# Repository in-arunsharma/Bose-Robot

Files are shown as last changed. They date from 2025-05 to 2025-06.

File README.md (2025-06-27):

# Bose: A Stair-Climbing Robot for Hybrid Terrain Navigation

**An open-source, low-cost robot designed to autonomously climb stairs and navigate flat indoor environments using adaptive locomotion and onboard perception.**

---

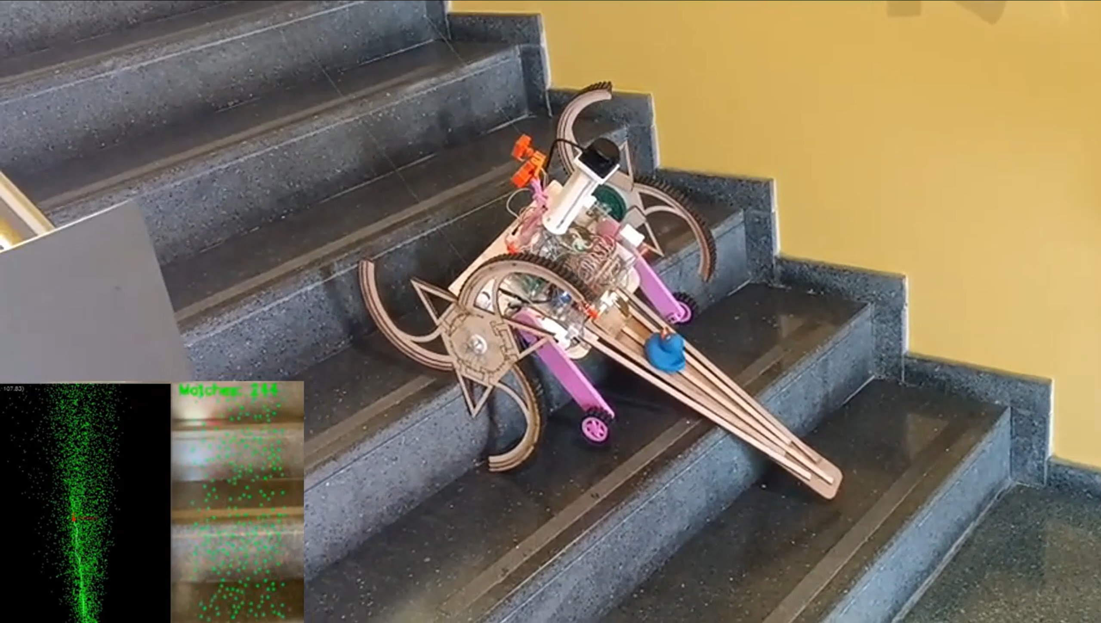
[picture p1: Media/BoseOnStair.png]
Bose Hero Image


---

## Table of Contents

- [Overview](#overview)
- [System Architecture](#system-architecture)
- [Repository Structure](#repository-structure)
- [Requirements](#requirements)
- [Installation](#installation)
- [Wiring and Setup](#wiring-and-setup)
- [How to Use](#how-to-use)
  - [Manual Control](#manual-control)
  - [SLAM and Navigation](#slam-and-navigation)
- [Mapping and SLAM](#mapping-and-slam)
- [Hardware Components](#hardware-components)
  - [Tri-Helix Wheels](#tri-helix-wheels)
  - [Retractable Wheels](#retractable-wheels)
  - [Support Tail](#support-tail)
- [Reproducibility](#reproducibility)
- [Citation](#citation)
- [Acknowledgments](#acknowledgments)
- [License](#license)

---

## Overview

**Bose** is a hybrid-terrain mobile robot capable of transitioning between stair-climbing and flat-ground modes through a custom tri-helix wheel system and retractable support wheels. Built around a Raspberry Pi 4 and designed for reproducibility and education, Bose combines real-time terrain classification, SLAM, and autonomous control in a lightweight, low-cost platform.

> 🧠 The robot is named after the **Bose-Einstein distribution**, reflecting its multi-modal adaptability and emergent behavior under constrained environments.

---

## Key Features

- Tri-helix wheel mechanism for stair traversal (up to 20 cm rise)
- Retractable micro wheels for efficient flat-ground navigation
- Real-time 2D SLAM with RPLIDAR C1 and monocular vision
- Terrain classification with ultrasonic sensor + camera
- Fully embedded system: runs on Raspberry Pi 4B (no external microcontroller)
- Modular, laser-cut chassis and 3D-printed mounts
- Reproducible architecture with open-source hardware and software

---

## Media & Demos

| Stair Climb | Terrain Switch | Visual SLAM |
|---|---|---|
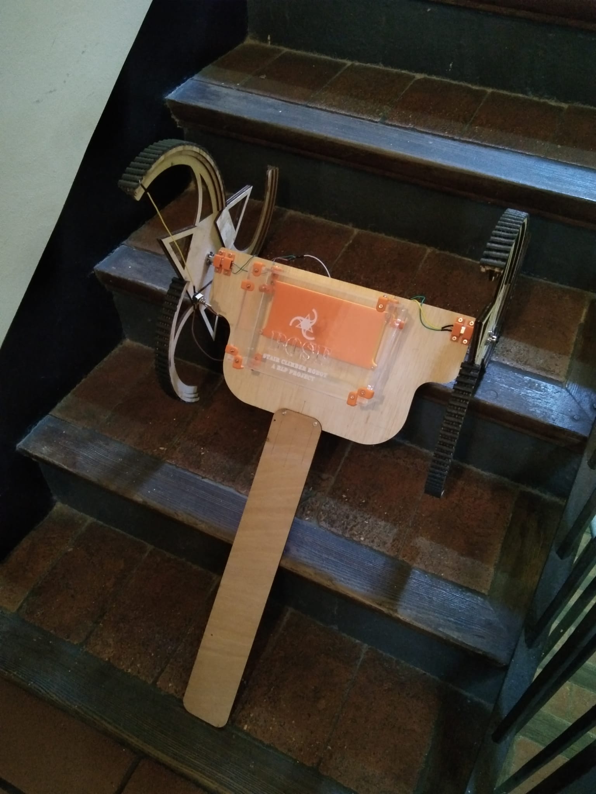
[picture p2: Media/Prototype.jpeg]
Stair Climbing
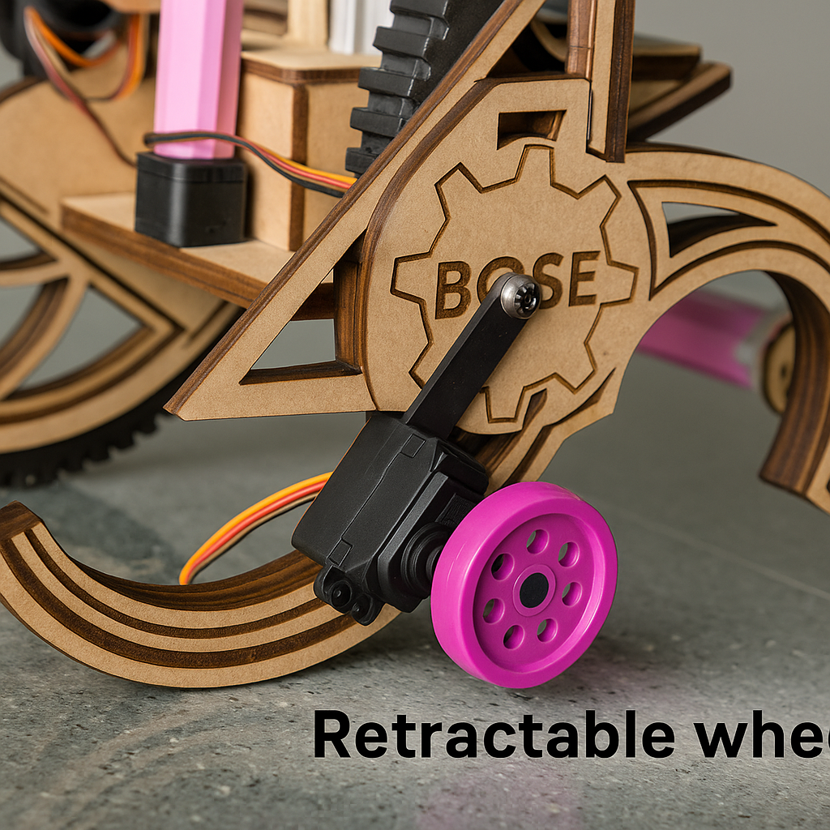
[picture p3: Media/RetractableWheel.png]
Terrain Switching
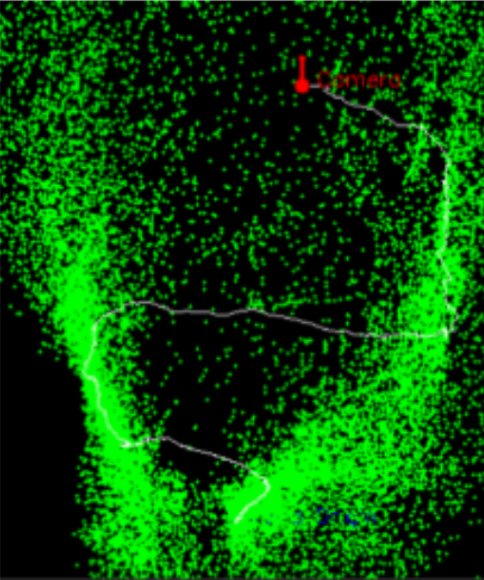
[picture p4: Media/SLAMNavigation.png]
SLAM Map
|  |  |  |

> See the full [demo video on YouTube](https://youtu.be/-nvnbL4hpCc)

---

## System Architecture

### Block Diagram

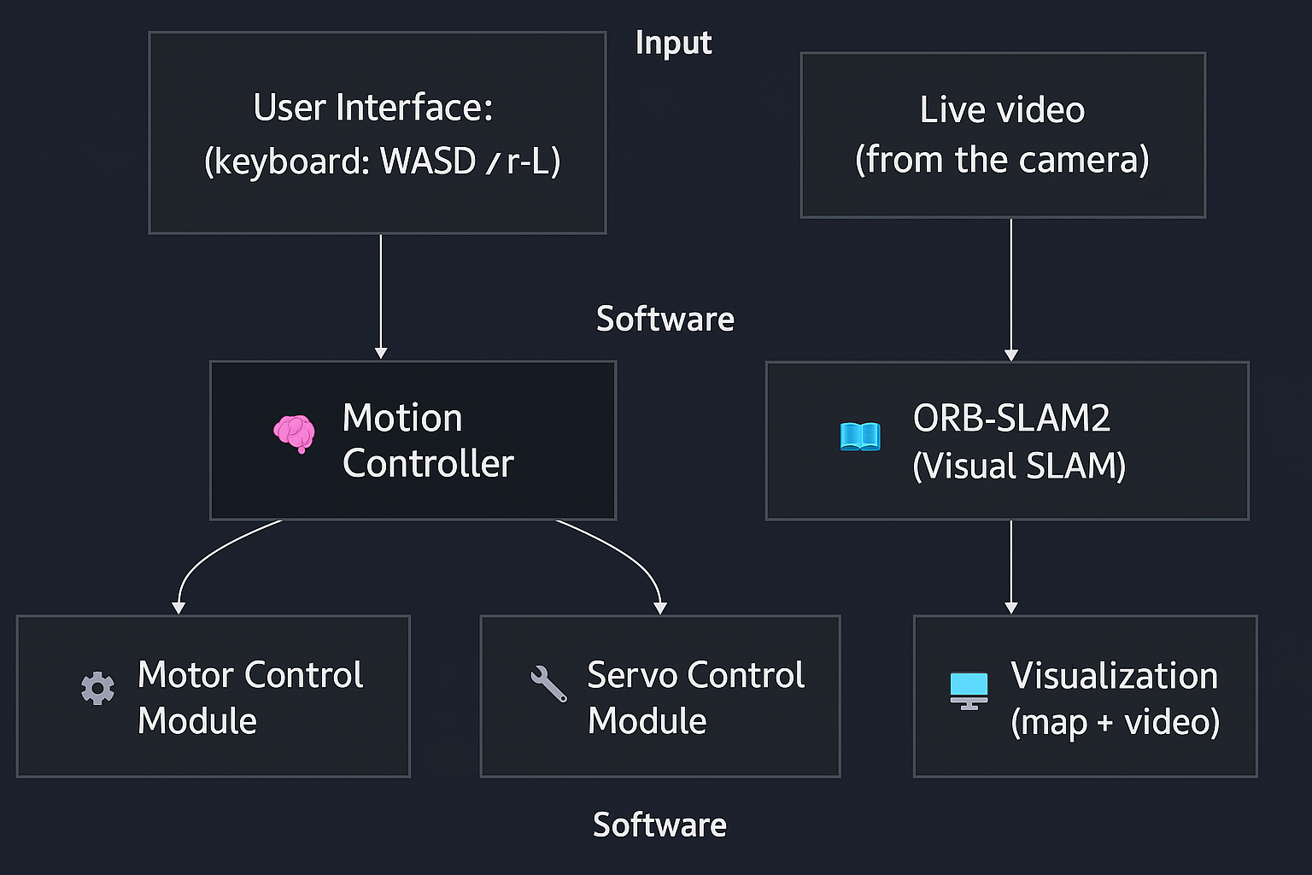
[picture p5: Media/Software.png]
System Architecture


### Hardware Stack

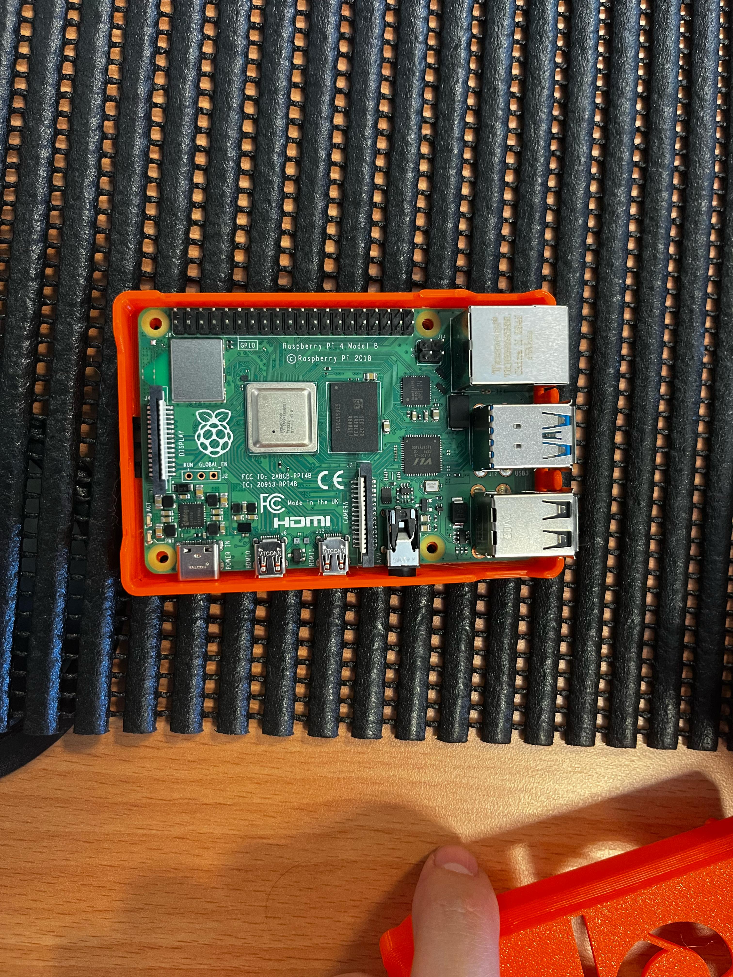
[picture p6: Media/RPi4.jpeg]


- Raspberry Pi 4B (4 GB RAM)
- MD25 Motor Controller (tri-helix wheels)
- L298N H-Bridge (retractable wheels)
- PCA9685 Servo Controller
- RPLIDAR C1 (USB)
- HC-SR04 Ultrasonic Sensor
- MPU6050 IMU
- Pi Camera v2 (8MP)
- 14.4V Li-ion Battery
- XL4015 and Pololu 5V 3A Buck Converters
- LEDs, push button, and MH Level Shifter

---

## 🛠️ Build Instructions

### Requirements

- Raspberry Pi 4B with Ubuntu 22.04
- ROS 2 Humble
- Python 3.10+
- Hardware: RPLIDAR C1, HC-SR04, MPU6050, PCA9685, MG996R servos, Maxon motors, etc.

Install dependencies:

```bash
sudo apt update && sudo apt install python3-pip
pip install adafruit-circuitpython-pca9685 smbus2 numpy opencv-python rplidar-robotics
```

## Repository Structure

```
├── docs/
│   └── logs/            # Logs of each working day
|   └── Paper.md         #IEEE Paper of the robot
├── hardware/
│   ├── Circuit/         # Fritzing schematics
│   └── DXF/             # 2D Drawings
|   └── STL/             # CAD models, STL files
├── software/
│   ├── raspberry4b-autonomous-lidar/           # Autonomus Code using RPLiDAR C1
│   ├── raspberry4b-remote/              # Manual Control Script
│   └── visual-slam/           # Visual SLAM Python Implementation
├── Media/                 # Photos and videos 
├── README.md
└── decisions.md           # Traceable engineering decisions
```

---

## Wiring and Setup

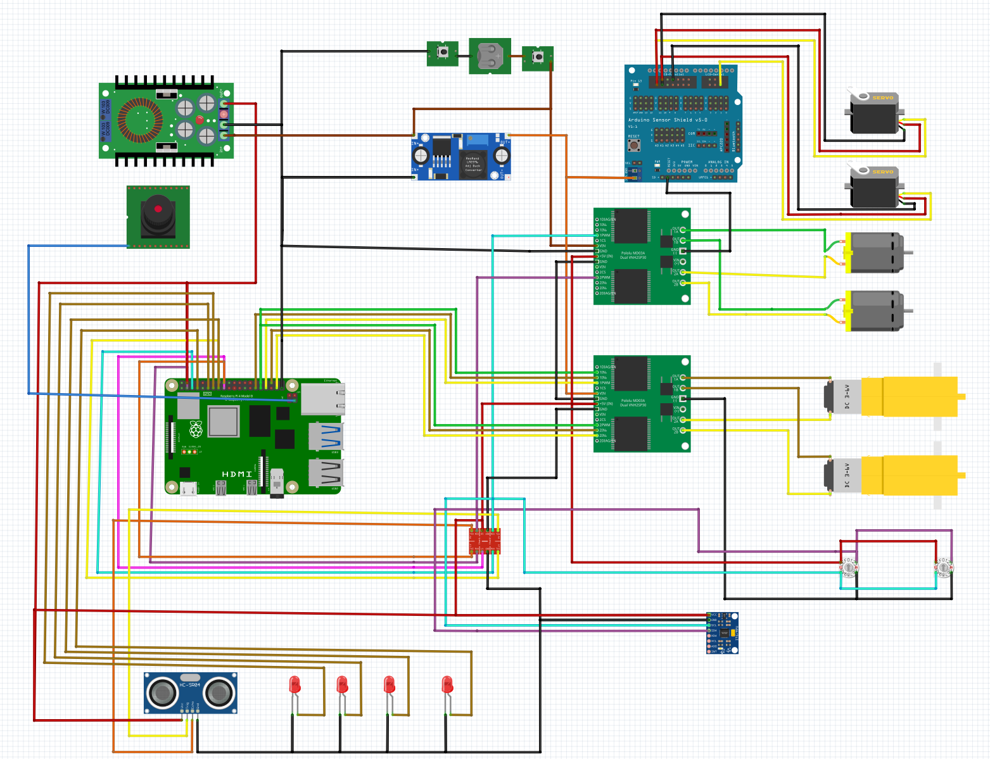
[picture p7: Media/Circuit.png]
BoseElectricCircuit

See `hardware/wiring_diagrams/raspberry_pi_wiring.pdf` for pinout.

> **Tip:** Use a 4700 μF capacitor near the Pi 5V rail to prevent brownouts during motor actuation.

---

## How to Use

### Manual Control (Interactive Script)

Run:

```bash
python3 scripts/interactive_control.py
```

**Controls:**

- Arrow keys: Helix motors  
- W / A / S / D: Retractable wheel motors  
- O / L: Lower / lift support wheels  
- Q: Quit

---

### SLAM and Navigation (ROS 2)

Launch ROS nodes:

```bash
source ~/ros2_ws/install/setup.bash
ros2 launch bose bringup.launch.py
```

**ROS 2 Topics:**

- `/scan` – RPLIDAR laser scan  
- `/odom` – Encoder-based odometry  
- `/imu/data_raw` – IMU orientation  
- `/camera/image_raw` – Pi camera feed

---

## Mapping and SLAM

Bose integrates:

- ORB-based monocular SLAM (via Pi Camera)
- 360º laser scanning (via RPLIDAR C1)
- Terrain detection (ultrasonic + vision)

A 2D occupancy map is built incrementally and used for localization and planning.

---

## Hardware Components

### Tri-Helix Wheels
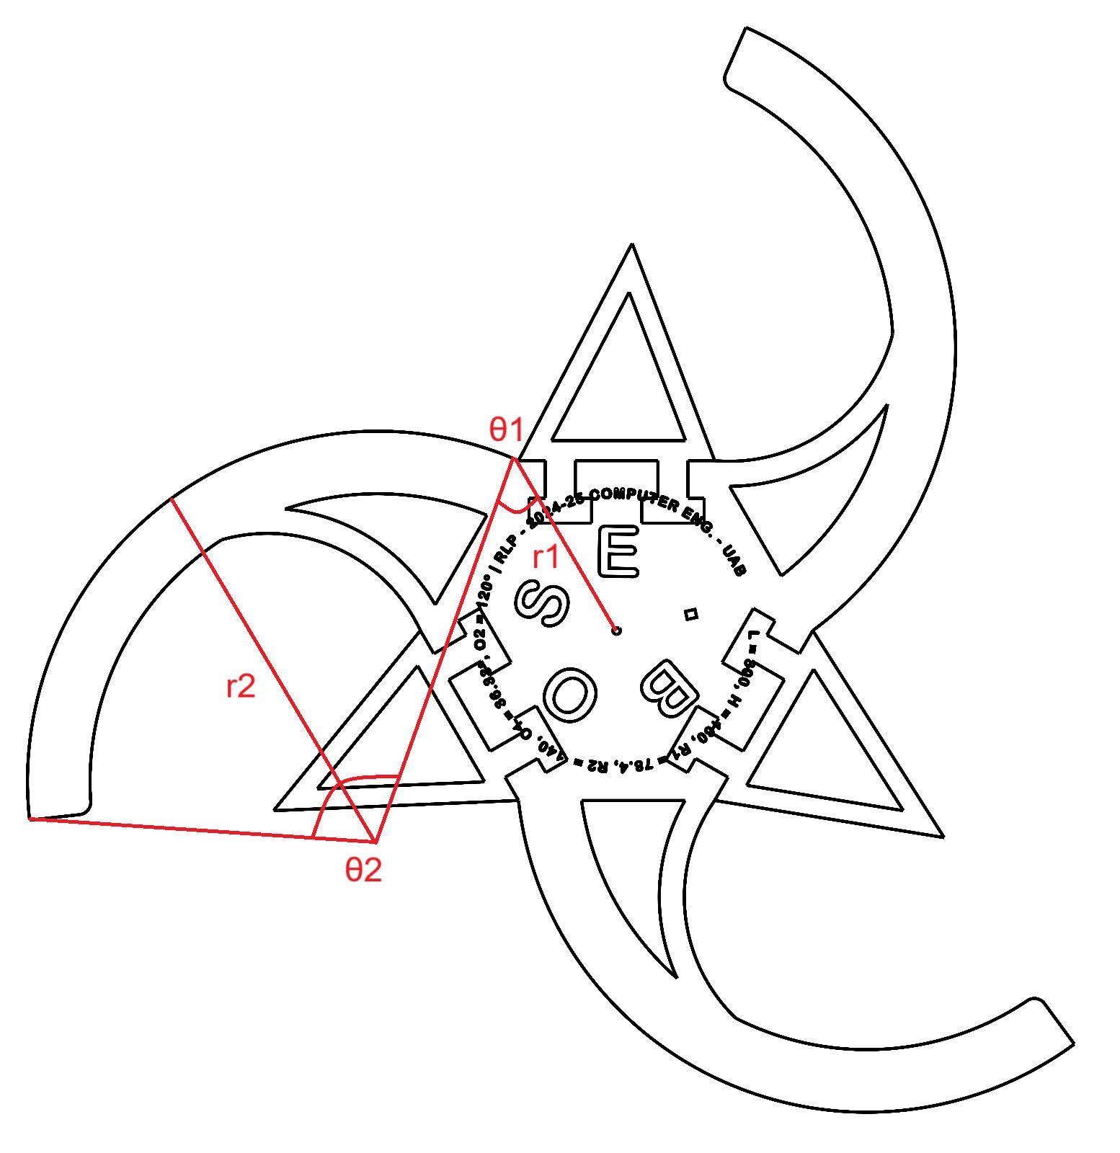
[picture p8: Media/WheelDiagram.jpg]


Laser-cut, three-lobed wheels for continuous stair climbing. Driven by Maxon motors with 785:1 gear reduction.

### Retractable Wheels

Pololu micro motors and MG996R servos enable flat-ground movement when the tri-helix wheels are lifted.

### Support Tail

A fixed rear extension adds stability on stairs without needing extra sensors or actuators.

---

## Reproducibility

To reproduce the robot:

1. Follow hardware instructions (CAD + wiring)
2. Flash Ubuntu 22.04 and install dependencies
3. Run the test scripts (manual or ROS-based)
4. Use `decisions.md` to trace engineering rationale

All firmware-free and open hardware. See `LICENSE`.

---

## Citation

**Arun Sharma**, **Pau Domínguez Ruiz**, **Gerard Souto Eslava**, **Chengjie Peng Lin**,  
*“Bose: A Stair-Climbing Robot for Hybrid Terrain Navigation,”* Universitat Autònoma de Barcelona, 2025.

```bibtex
@misc{bose2025,
  author      = {Sharma, Arun and Domínguez Ruiz, Pau and Souto Eslava, Gerard and Peng Lin, Chengjie},
  title       = {Bose: A Stair-Climbing Robot for Hybrid Terrain Navigation},
  year        = {2025},
  institution = {Universitat Autònoma de Barcelona},
  note        = {Bachelor’s Course in Computer Engineering}
}
```

---

## Acknowledgments

- Prof. Fernando L. Vilariño Freire  
- Prof. Carlos G. Calvo  
- Prof. Vernon S. Albayeros Duarte  
- Open Labs – Escola d’Enginyeria, UAB  
- Maxon Spain and Robot Electronics support teams

---

## License

This repository is licensed under the MIT License. See `LICENSE` for details.

> For academic use, extension, or replication, please contact the authors or contribute via GitHub issues and pull requests.

---

_"To climb stairs is to rise beyond limits. Bose takes that literally."_

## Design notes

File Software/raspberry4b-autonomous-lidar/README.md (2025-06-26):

# Exploración Autónoma 🧭

Este script busca que BOSE, equipado con un **RPLiDAR C1 – 360°**, explorar de forma autónoma y segura entornos potencialmente peligrosos (zona de rescate, desastres, entornos de riesgo, etc.).

- Realiza un **mapeado 2D en tiempo real** del entorno.  
- Se mueve tipo "Roomba": avanza, detecta obstáculos y cambia de rumbo.  
- Genera una visualización gráfica del mapa y del recorrido del robot.  
- Se basa en el controlador del motor MD25 y el sistema de LIDAR.

---

## Requisitos

- Python 3  
- Paquetes necesarios:
  ```bash
  pip3 install smbus2 numpy matplotlib rplidar

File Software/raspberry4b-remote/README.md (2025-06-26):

# Manual Control Script

Este script (`manual_control.py`) permite manejar a BOSE en Raspberry Pi 4 con:

1. **Tracción principal** (MD25) con teclas W/A/S/D  
2. **Ruedas retráctiles** (L298N) con flechas ↑/↓  
3. **Servos** (PCA9685) con O (subir) / L (bajar)  
4. **Salir** con E o Ctrl+C (detiene todo y limpia GPIO/I²C)

---

## Requisitos

- Python 3  
- Módulos:
  ```bash
  pip3 install smbus2 RPi.GPIO adafruit-circuitpython-pca9685 inputs

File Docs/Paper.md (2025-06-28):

# Bose: A Stair-Climbing Robot for Hybrid Terrain Navigation

**Arun Sharma**, **Pau Domínguez Ruiz**, **Gerard Souto Eslava**, and **Chengjie Peng Lin**  
School of Engineering, Universitat Autònoma de Barcelona, 08193 Bellaterra, Spain^[This project was completed as part of the bachelor’s course *Robotics, Language and Planning* (Spring 2025) in the Bachelor’s Degree programme in Computer Engineering.]
 
---

## Abstract
This paper presents Bose, a novel stair-climbing robot featuring an adaptive-wheel mechanism optimized for hybrid-terrain navigation. Addressing practical challenges in accessibility and autonomous indoor exploration, Bose employs two laser-cut tri-helix wheels for stair traversal, combined with smaller retractable wheels that activate during flat-surface navigation. An  tail mechanism maintains stability across diverse terrains. The robot integrates multiple onboard sensors, including an inertial measurement unit, ultrasonic range sensors, encoders, camera, and a 2D LiDAR, enabling terrain-aware locomotion and environment mapping. Terrain detection leverages computer vision and distance sensing, dynamically adjusting the wheel configuration based on real-time feedback. Key mechanical and control challenges, such as achieving sufficient torque-to-weight ratios and reliable transition between wheel modes, were systematically addressed. Experimental evaluations demonstrate Bose’s capability to autonomously climb standard stairs (up to 20 cm rise and 35° incline) and smoothly transition onto flat terrain at speeds up to 0.08 m/s. Additionally, real-time simultaneous localization and mapping (SLAM) facilitates autonomous navigation in unknown indoor environments. Future improvements will focus on enhancing adaptability through shape-shifting wheels capable of accommodating varied stair geometries, eliminating redundant wheel systems, and refining structural aerodynamics.
---
**Index Terms—** stair-climbing robot; tri-helix wheel; adaptive locomotion; hybrid-terrain navigation; low-cost robotics; SLAM.

---
## 1. Introduction
Mobile robots capable of traversing stairs unlock critical applications in urban logistics, assistive technologies, and disaster response. Current solutions, including tracked platforms such as the iRobot 510 PackBot [1][2] and legged systems like ANYmal [3], often exhibit significant trade-offs among speed, cost, and mechanical complexity. For instance, tracked robots typically climb standard stairs at speeds below 0.04 m·s⁻¹, while advanced quadrupedal robots rely on 12–18 high-precision actuators, elevating unit costs into the tens of thousands of USD.

This paper introduces **Bose**, a low-cost robotic platform designed to autonomously and efficiently navigate hybrid terrains—flat surfaces and stairways—by employing a novel adaptive wheel mechanism. Unlike conventional tracked or purely legged solutions, Bose utilizes laser-cut tri-helix wheels specifically optimized for rapid stair traversal, complemented by small retractable wheels activated for efficient flat-ground navigation. Terrain-adaptation is achieved through real-time fusion of monocular vision, ultrasonic ranging, wheel odometry, and 2D LiDAR data, enabling transitions between wheel modes in under 50 ms. A custom drivetrain delivers a peak torque of approximately 10 N·m per 0.22 m diameter wheel, keeping total mass below 3 kg and material costs under 500 USD.

The primary contributions of this work are threefold:

- An adaptive wheelset mechanism that doubles stair-climbing speed compared to tracked robots of similar mass.
- A lightweight perception stack capable of achieving terrain-classification accuracy above 95%, implemented on a Raspberry Pi 4.
- An open-source hardware and software framework facilitating replication and further research.

Experimental validation conducted on standard stairs (16 cm rise, 30 cm tread) demonstrated reliable ascent and descent at speeds up to 0.08 m·s⁻¹, maintaining pitch deviations below 5°. Additionally, Bose navigated 50 m of mixed indoor terrain without human intervention.

The robot is named Bose, inspired by the Bose–Einstein distribution—an allusion to its multi-modal adaptability and emergent behavior under constrained conditions. Like the physical phenomenon, the robot seeks to exhibit coherent, unified responses across varying environments.

The remainder of the paper is structured as follows: Section 2 provides a review of related work. Section 3 describes the proposed robotic architecture. Sections 4–6 detail mechanical, electronic, and software design. Sections 7 and 8 present the experimental methodology and corresponding results. Section 9 discusses the broader implications of these findings. Section 10 concludes the paper and highlights avenues for future development.

---
## 2. State of the Art

Stair negotiation remains an open problem in mobile robotics. Prior work spans six mechanical paradigms, each trading off speed, cost, and fabrication complexity. Below we summarise the dominant approaches and assess their suitability for low-cost academic prototypes.

### 2.1 Lifting or Pivot-Hoist Platforms  
Early robots such as CMU’s URBOT (1993) elevate the chassis with powered arms to surmount each step. Although conceptually simple, hoist mechanisms demand >20 N m joint torques and suffer cycle times of 6–10 s per step, limiting practicality on long staircases [4].

### 2.2 Pure Traction Wheels  
Four-wheel differentially driven platforms rely on tyre friction and wheelbase shift (e.g., Asguard V2 [5]). They are lightweight (<3 kg) but stall on 17 cm stair risers unless equipped with exotic rubber compounds or active suspension.

### 2.3 Articulated Multi-Wheel Sets  
Six-wheel rovers with rocker-bogie or flipper arms (e.g., the Mars Exploration Rover mobility system [6]) add contact points and passive compliance. Complexity rises sharply: typical hobby-grade builds require 12 bearings and 4 gearboxes, yet still climb stairs at ≤0.05 m s⁻¹.

### 2.4 Helical Tri-Wheel Mechanisms  
Tri-star and spiral wheels rotate successive lobes onto the next tread, enabling quasi-continuous ascent. NASA’s Athlete and the TriStar prototype [7] reach 0.08–0.12 m s⁻¹ on 17 cm stairs while using a single drive motor per side. Drawbacks are high peak torque (~10 N m) and manufacturing of curved lobes—now alleviated by low-cost laser-cut laminates.

### 2.5 Tracked (Caterpillar) Systems  
PackBot 510 [1],[2] typifies track-based climbers: excellent adhesion and load capacity but speeds below 0.05 m s⁻¹ and a bill-of-materials exceeding USD 10 k. Track tensioners and suspension arms add weight (>10 kg) beyond most classroom resources.

### 2.6 Legged Platforms  
Quadrupeds such as ANYmal [3] or Boston Dynamics Spot rival human stair speed (0.5 m s⁻¹) and handle irregular steps. However, they rely on 12–18 Series Elastic Actuators and GPU-class onboard computing, pushing cost to USD 75 k+.

### 2.7 Design Choice  

| Architecture | Iconic robot (ref) | Step height tested | Speed on 17 cm stairs | Cost tier | Key drawbacks |
|---|---|---|---|---|---|
| Pivot-hoist  | URBOT [4] | 18 cm | 0.10 m s⁻¹ (one step / 8 s) | $$ | High torque, cycle time |
| Pure wheels  | Asguard V2 [5] | 15 cm | 0.03 m s⁻¹ | $  | Slips on smooth treads |
| Rocker-bogie | MER rover [6] | 22 cm (lab) | 0.05 m s⁻¹ | $$ | Heavy, 12 bearings |
| Tri-wheel | Curved-spoke [7]  | 17 cm | 0.10 – 0.12 m s⁻¹ | $  | 10 N·m peak torque |
| Tracks | PackBot 510 [1] | 20 cm | 0.04 m s⁻¹ | $$$ | 10 kg chassis |
| Quadruped | ANYmal [3] | 18 cm | 0.5 m s⁻¹ | $$$$ | 12 SEAs, GPU |

Table 1

Considering the above, the **helical tri-wheel** offers the best cost-to-performance ratio for our constraints: (i) continuous ascent at ≈0.08 m s⁻¹, doubling tracked alternatives; (ii) only two drive motors; (iii) fabrication via 3 mm plywood laser-cuts within a USD 500 budget. We therefore adopt a spiral tri-helix wheel combined with retractable micro-wheels for flat terrain.

---
## 3. Proposed Architecture

### 3.1 System Overview

Bose is a semi-autonomous mobile robot designed for hybrid indoor environments, capable of transitioning between flat-ground locomotion and stair climbing. The system is built around a Raspberry Pi 4B, which performs all sensing, perception, control, and actuation logic. The robot supports two control modes: (i) autonomous navigation, wherein it constructs a map of the environment using onboard sensors and receives a goal position from the user; and (ii) manual mode, primarily used for system testing and teleoperated control.

The mechanical architecture consists of a pair of custom tri-helix wheels, each driven by a high-torque DC motor through a planetary gearbox with a 780:1 reduction ratio. This configuration provides the necessary torque for ascending standard staircases. For flat-ground navigation, two auxiliary wheels actuated by Pololu Micro Metal Gearmotors (150:1 ratio) can be deployed. These small-diameter wheels are mounted on motorized arms and serve to lift the tri-helix wheels off the ground, effectively switching the drivetrain for improved maneuverability on flat terrain. A static tail structure provides additional stability but does not contain any actuators.

Power is supplied by a 14.4 V lithium-ion battery pack. Two dedicated buck converters regulate voltage rails: one supplies a stable 5 V at 3 A to the Raspberry Pi and all sensors, including the 2-D LiDAR, monocular camera, ultrasonic sensor, and MPU-6050 IMU; the other provides appropriate voltage and current to the retractable wheel motors and servos. The primary climbing motors are driven directly via an H-bridge rated for the main battery voltage. Wheel encoders are installed on the tri-helix motors only, providing rotational feedback for closed-loop control.

All computation, decision-making, and sensor fusion take place onboard the Raspberry Pi 4B running Ubuntu 22.04 with ROS 2 Humble. No external control units or communication networks are required during operation.

### 3.2 Subsystem Integration

The robot architecture is divided into three main subsystems: mechanical, electrical, and software.

The mechanical subsystem includes the laser-cut chassis, tri-helix wheels, retractable wheel assemblies, and static tail. The wheelsets are designed for rapid mode-switching via control logic and physical actuation, allowing the robot to traverse both stairs and smooth surfaces without user intervention.

The electrical subsystem comprises the 14.4 V lithium-ion battery, dual buck converters, motor drivers, and sensor suite. All sensor and actuator lines terminate at the Raspberry Pi, which handles signal acquisition and control through standard GPIO, PWM, and I2C interfaces. The IMU provides orientation and acceleration data, while the LiDAR supplies spatial information for SLAM. The system uses wheel encoder pulses to estimate displacement during terrain transitions.

The software subsystem orchestrates perception, planning, and control. ROS 2 Humble acts as the middleware, managing inter-node communication. A SLAM module fuses LiDAR and camera input to generate a 2-D occupancy grid and maintain localization. Terrain classification routines process camera and ultrasonic data to determine whether the robot is on flat ground or approaching stairs. Depending on the terrain class, a locomotion controller activates the appropriate drivetrain. The system also includes a route planner that responds to user-specified goals and generates feasible trajectories. Low-level motor commands are executed via a dedicated ROS node communicating with the H-bridge drivers.

### 3.3 Functional Diagram

Figure 1 presents the high-level functional architecture of the system. The flow begins with user input or goal specification, which feeds into the route planning module. This module interacts with a SLAM-based localization system to build and refine the global map. A terrain-aware motion controller processes the path plan and real-time sensor data to determine the most appropriate locomotion mode. This logic produces velocity and actuation commands that are sent to the motor control layer, which in turn drives the climbing or retractable wheels.

The software stack operates in a closed-loop configuration, with real-time feedback from encoders, IMU, and LiDAR continuously updating the robot’s state estimate. The system is designed to be modular, allowing for future upgrades such as wireless teleoperation, additional sensor modalities, or dynamic stair height adaptation.

---

## 4. Mechanical Design

The mechanical design of *Bose* plays a fundamental role in enabling its stair-climbing capabilities and hybrid-terrain adaptability. This section details the structural configuration, wheel layout, support elements, and component integration strategies that allow the robot to navigate architectural stairs and flat surfaces. Design priorities included maximizing torque transmission, minimizing total mass, ensuring manufacturability with low-cost materials, and providing structural stability during vertical ascent. Each subsystem—chassis, wheels, support mechanism, and electronics enclosure—is described in the following subsections.

### 4.1 Frame and chassis
The mechanical architecture of Bose was driven by the need for weight efficiency, spatial simplicity, and compatibility with stair-step geometries. The robot adopts a planar T-shaped frame layout, with the main electronics, drivetrain, and wheel mounts integrated into a single-layer chassis cut from 4 mm laser-cut plywood. Structural reinforcement and mounting were achieved via 3D-printed brackets and spacer blocks.

The approximate overall dimensions of the chassis are 800 mm × 550 mm, with the long axis aligning with the direction of motion. The central crossbar serves as the load-bearing anchor for the helix wheel axles, while the rear extension (“tail”) provides pitch stability during ascent phase. To reduce flexion in this tail segment, four wooden reinforcement strips (15 mm × 4 mm × 500 mm) were bonded along the sides using cyanoacrylate adhesive.

All delicate electronic components, including the Raspberry Pi, motor controllers (MD25, L298N), and I²C servo interface — are mounted inside a transparent acrylic enclosure fixed atop the central chassis. This enclosure is elevated approximately 15 mm above the frame base, allowing clearance for uneven PCB bottoms and screw heads. Mounting was achieved via machine screws on embedded 3D-printed spacers, avoiding vibrations and maintaining access for debugging and maintenance.

The enclosure also provides the structural base for the LiDAR mast, which is elevated to a height that ensures the scan plane remains unobstructed by the rotating helix wheels. Sensor stands for the ultrasonic sensor and camera were likewise 3D-printed to specific angles and distances for optimal stair detection coverage.

Load distribution is concentrated on the tri-helix wheel axis, which supports the primary mechanical torque and weight of the robot. There is no suspension or active vibration damping mechanism; however, empirical tests revealed minimal frame oscillations during both flat-ground and stair-climbing operation. This validates the suitability of plywood for the current prototype, where lightweight fabrication and rapid iteration were prioritized over ruggedization.

### 4.2 Wheel Configuration

Bose employs a curved tri-helix wheel system, inspired by [10], that enables continuous stair climbing by transforming rotary motion into an ascending gait. Each wheel consists of three curved spokes spaced 120° apart, laser-cut from 4 mm plywood and laminated with two lateral reinforcement layers, yielding a 20 mm wide tread. At the contact point of each lobe, a rubber-patterned foam contact patch enhances traction and minimizes slippage on stair edges.

To ensure phase synchrony during multi-step ascent, each curved lobe is mechanically coupled to a passive triangular stopper. These triangular components are formed from two stacked plywood layers (total 8 mm) and covered with transparent adhesive film to reduce friction. As a result, each stair climb begins from a stable, repeatable pose, improving the precision and linearity of center-of-rotation (CoR) trajectories.

Following [10], we applied the kinematic analysis for optimal wheel geometry based on the most common stair dimensions in our operating environment: tread length l = 300 mm, riser height h = 160 mm, and segment angle θ₂ = 120°. The required parameters—hub radius r₁, lobe radius r₂, and spoke angle θ₁—are derived from:

$$
\begin{aligned}
    l = r_2 \Bigl(\theta_2 - \frac{\sqrt{3}}{2}\Bigr) + r_1 \bigl(\sin \theta_1 - \sin(\theta_1 - \theta_2)\bigr) \\
    h = \frac{3}{2} r_2 + r_1 \bigl(-\cos \theta_1 + \cos(\theta_1 - \theta_2)\bigr) \\
    \frac{2}{3} \pi r_2 < l
\end{aligned}
$$

Using the above, we selected r₂ = 143 mm, r₁ = 78 mm, and θ₁ = 36,33°, providing a CoR trajectory closely aligned with a straight line. The resulting wheel profile enables smooth, vibration-minimized stair climbing with high stability.

Each wheel is driven by a Maxon DC motor coupled with a 157:1 planetary gearbox and an external 5:1 gear stage, yielding an effective reduction of 785:1. This provides sufficient torque to lift the robot’s mass (~5 kg) against gravity during step ascent. Encoders mounted on the drive shafts enable feedback control for velocity and position tracking.

The wheels are fabricated using modular laser-cut geometry for rapid iteration, and mounted via keyed aluminum hubs onto the motor shafts. All components are fastened using M3 screws and epoxy-sealed at high-load points to ensure mechanical integrity during impact-rich stair traversal.

> **Note:** A separate support system using retractable wheels enables efficient motion on flat terrain. This is discussed in Section 4.3.

### 4.3 Support mechanism
To enhance mobility on flat terrain, Bose incorporates a pair of rear-mounted retractable micro wheels driven by Pololu 150:1 gearmotors. These wheels are deployed via MG996R servos connected to custom 3D-printed arms. While the servos are not strong enough to lift the robot directly from a full rest state, a two-phase assistive strategy was developed to enable lifting:

1. The robot begins with its tri-helix wheels at a tilted stance (single point of contact), leaving maximum clearance below the chassis.

2. The servos lower the support arms and small wheels until they touch the ground.

3. A slight rotation of the helix wheels shifts the chassis into a balanced two-point stance, allowing the support arms to passively hold the frame above ground using their longer geometry.

The same principle is reversed to retract the wheels when stair traversal is re-activated. This lifting mechanism is controlled either automatically—through terrain sensing using vision and ultrasonic fusion—or manually using key-based remote commands during testing.

The retractable arms are fabricated in PLA and are structurally designed to bear load by leaning against the underside of the base frame once lowered. This avoids relying entirely on servo torque. The support wheels themselves are surfaced with the same patterned rubber-foam grip material used on the tri-helix wheels to ensure consistent traction.

The retractable support system significantly improves speed, power efficiency, and trajectory stability during flat-ground navigation, where helix rotation would otherwise introduce wobble and drag.

### 4.4 Mounting and integration

The physical integration of *Bose*'s components was optimized for modularity, structural safety, and ease of assembly. Custom 3D-printed housings were used to secure the main drive motors (Maxon 110055 with 157:1 gearheads), which are coupled to the tri-helix wheels via externally mounted 7:1 plastic reduction gears. The gear shafts are aligned using fixed axles embedded in the plywood chassis, with no suspension or bearing isolation—relying instead on the high torque and low RPM to ensure mechanical stability.

Electronic components are installed inside a laser-cut acrylic enclosure, supported by precision-cut standoffs and M3 fasteners. This modular box enables rapid replacement of core modules such as the Raspberry Pi, motor drivers, and servo controller without disturbing the main frame. Wiring is routed cleanly using different colors for easy differenciation.

Sensor elements, including the ultrasonic sensor, camera, and LiDAR, are mounted on **dedicated, height-adjustable PLA stands**. These mounts are designed to preserve calibration and alignment while remaining detachable for maintenance. All fixtures rely on screws or interlocking tabs rather than adhesives, in line with open-lab prototyping principles.

The complete assembly strategy prioritizes rapid repair, physical robustness during stair traversal, and spatial separation between high-power and sensor-level subsystems.

---

## 5. Electronics and Sensors
The electronic system of *Bose* was designed to support high-torque actuation, multi-sensor terrain detection, and autonomous behavior within a compact, power-efficient embedded setup. All components interface directly with a Raspberry Pi 4B, which serves as the main controller running ROS 2 and coordinating sensor input, actuator control, and decision logic. Power is distributed via two independent buck converters, while onboard logic-level shifting ensures safe communication with 5 V peripherals. This section describes the power architecture, motor drivers, control hardware, and sensing subsystems integrated into the robot.

### 5.1 Power System

The entire robotic platform is powered by a **4-cell (4S) lithium-ion battery pack**, providing a nominal voltage of **14.4 V** and a capacity of **2200 mAh**. Power distribution is handled via two dedicated DC-DC converters:

- An **S13V30F5 buck-boost regulator** delivers a fixed **5 V / 3 A** max output to power the Raspberry Pi 4B and all 5 V logic-level sensors, including the IMU, ultrasonic rangefinder, and I2C servo controller.
- A high-current **XL4015 step-down regulator** supplies the necessary voltage and current for the retractable wheel motors and servo actuators.

To protect the control subsystem against voltage dips during high-load transitions (e.g., simultaneous motor startup), a **4700 μF / 16 V electrolytic capacitor** is placed near the 5 V rail input of the Raspberry Pi. A double-switch mechanism isolates the battery pack from the full circuit for safety and debugging.

### 5.2 Motor Drivers

The actuation system is divided into two independent motor driver circuits:

- The **MD25 motor controller** is responsible for the two tri-helix drive motors. It communicates via I²C and internally manages encoder feedback and speed regulation. The MD25 also provides real-time battery voltage readout, which is used to control status indicators on the robot.
- The **L298N H-bridge module** controls the retractable wheel motors using standard **PWM and GPIO signals** generated by the Raspberry Pi. Directional control and enable lines are mapped to dedicated pins, allowing dynamic activation and deactivation of the flat-ground drive system.

All drivers are interfaced through open-source libraries, with ROS 2 nodes abstracting low-level communication. The MD25 is treated as a composite controller due to its integrated quadrature encoder decoding and internal PID logic.

### 5.3 Main Controller

The entire system is orchestrated by a **Raspberry Pi 4B (4 GB RAM)** running **Ubuntu 22.04** with **ROS 2 Humble**. It handles all sensor acquisition, actuator control, terrain classification, SLAM computation, and decision-making onboard—no external microcontroller is used.

To safely interface the Pi’s 3.3 V GPIO logic with 5 V peripherals, a **bi-directional MH level shifter** is used. This converts voltage levels for the **HC-SR04 ultrasonic sensor’s echo pin**, the **MPU6050’s optional INT pin**, and the **I²C bus**, which serves multiple 5 V sensors and controllers.

The Pi communicates directly with:
- MD25 (I²C)
- PCA9685 (I²C)
- L298N (PWM + GPIO)
- Camera module (CSI)
- RPLiDAR C1 (USB)
- GPIO-driven peripherals (LEDs, push button)

### 5.4 Sensors

#### IMU
An **MPU6050 gyroscope and accelerometer** is connected via I²C, providing 6-DOF motion data. Although the module includes an INT pin, it is not used in the current implementation. The IMU is primarily employed for orientation estimation and future fall detection.

#### Wheel Encoders
Quadrature encoders are embedded in the Maxon drive motors and routed through the MD25 controller. Encoder ticks are read directly over I²C, enabling closed-loop velocity and displacement estimation during stair climbing.

#### LIDAR
An **RPLiDAR C1** unit provides 360º spatial mapping data via USB, interfaced using the official Slamtec SDK. It supports the SLAM and localization stack under ROS 2 and is physically mounted above the chassis to avoid interference from the rotating wheels.

#### Ultrasonic Sensor
An **HC-SR04 ultrasonic rangefinder** is used for stair detection in the forward direction. Its echo line is routed through the MH level shifter before reaching a Raspberry Pi GPIO pin to comply with 3.3 V logic tolerance.

#### Camera
The system includes a **Raspberry Pi Camera Module v2 (8 MP)** connected via CSI. It is used in terrain classification and stair detection through monocular vision and supports future upgrades such as AprilTag localization or CNN inference.

#### Status LEDs and Push Button
Four status LEDs (red, green, blue, and transparent) are connected via GPIO with current-limiting resistors and used to indicate motor states, battery level, or error conditions. A single normally-open push button is also connected to a GPIO input to trigger start/stop commands locally without requiring a remote interface.

---

## 6. Software Design

The software stack for BOSE is designed to support autonomous hybrid-terrain navigation, real-time sensor fusion, and visual Simultaneous Localization and Mapping (SLAM). All components execute onboard the Raspberry Pi 4B using ROS 2 Humble under Ubuntu 22.04. The architecture prioritizes modularity and real-time responsiveness within the constraints of limited embedded compute resources.

### 6.1 Control Structure

The control framework follows a layered architecture:

- **User Interface Layer:** Accepts navigation goals or manual commands (via keyboard or GUI).
- **Planning Layer:** Translates goals into global paths using the local map and updates via SLAM.
- **Motion Control Layer:** Generates real-time velocity and actuation commands, adjusting motor output based on terrain type.
- **Hardware Abstraction Layer (HAL):** Interfaces with sensors and motor drivers, wrapping hardware access into ROS 2 nodes.

ROS 2 nodes communicate through DDS middleware, enabling asynchronous sensor updates, real-time control loops, and topic-based data sharing.

### 6.2 Communication Protocols

- **I²C** is used for MD25 (tri-helix motors + encoder feedback), MPU6050 (IMU), and the PCA9685 servo controller.
- **PWM + GPIO** control is used for the retractable wheel motors and status LEDs.
- **USB** connects the RPLIDAR C1.
- **CSI** interfaces the Pi camera module.
- **Standard ROS 2 Topics and Services** handle internal message passing between motion planners, SLAM, and actuator modules.

### 6.3 Motion Control Logic

The robot switches dynamically between **stair-climbing mode** and **flat-ground mode**. This transition is determined by terrain classification using the camera and ultrasonic sensor. On stairs, the tri-helix motors are enabled and drive the robot with constant torque. On flat surfaces, the retractable micro wheels are lowered, and the tri-helix wheels are lifted to reduce friction and improve efficiency.

The control algorithm includes:

- Encoder-based closed-loop speed regulation (via MD25)
- PWM ramping for smoother actuation on L298N
- Terrain-based mode switching with safety delays
- Key-press override for manual mode control

### 6.4 Sensor Integration

All sensor readings are time-synchronized and published as ROS 2 topics:

- **IMU data** provides inertial feedback for attitude estimation.
- **Encoders** track wheel rotation for odometry.
- **Ultrasonic readings** inform stair distance estimation and elevation changes.
- **Camera images** feed the SLAM pipeline and reused for terrain classification.

Each sensor is independently filtered and abstracted to reduce coupling between hardware and logic layers.

### 6.5 SLAM and Terrain Awareness Module

The robot integrates a lightweight, multi-sensor SLAM and terrain awareness system to enable autonomous navigation in unknown environments. The core of this module is a **monocular visual SLAM pipeline**, supported by **LiDAR**-based obstacle detection and **ultrasonic sensing** for terrain classification and step detection.

#### Visual SLAM Pipeline (Camera-Based)

The visual SLAM system uses sequential frames from the Raspberry Pi Camera Module v2 to estimate motion and build a sparse map of the environment:

1. **Initialization:** Detects ORB (Oriented FAST and Rotated BRIEF) features in the first frame and computes descriptors.
2. **Feature Tracking:** Matches these features between consecutive frames using descriptor similarity.
3. **Relative Pose Estimation:** Computes the relative rotation and translation between frames using epipolar geometry and essential matrix decomposition.
4. **Triangulation:** Reconstructs a 3D point cloud from matched keypoints using triangulation.
5. **Incremental Mapping:** Maintains a trajectory estimate and expands the point cloud over time using keyframes.
6. **Keyframe Management:** Selects new keyframes based on motion thresholds (distance or angular change) to improve tracking stability.

Although the core SLAM map is three-dimensional, the current implementation visualizes it as a 2D projection to reduce computation and allow real-time performance on embedded hardware.

#### LiDAR Integration

The RPLIDAR C1 is used to augment the SLAM system by providing high-frequency 2D laser scans for real-time obstacle detection and short-range localization. Unlike the monocular SLAM pipeline, which builds a longer-term map based on keyframes and camera motion, the LiDAR sensor delivers instantaneous spatial data with uniform angular resolution. This information is particularly valuable for detecting walls, stair edges, and floor transitions during navigation.

All LiDAR data is published as standard LaserScan messages under ROS 2, enabling integration with visualization tools and local path-planning nodes. The LiDAR’s 360-degree coverage ensures that the robot maintains situational awareness regardless of its orientation, which improves safety during stair climbing and allows accurate occupancy grid construction on flat surfaces. By combining LiDAR and visual SLAM data, the system achieves a balance between geometric precision and environmental density in its internal representation.

#### Ultrasonic Terrain Classification

To enhance terrain recognition and state transitions, Bose also incorporates a HC-SR04 ultrasonic sensor mounted at the front of the chassis. This sensor provides direct distance measurements to the surface ahead, allowing the system to detect elevation changes such as stair treads, floor edges, or drops. Its measurements are fused with encoder readings and visual data to create a multi-modal classifier capable of triggering a locomotion mode switch.

When the ultrasonic sensor detects a sudden decrease in floor distance, it signals the control node to prepare for stair ascent and activates the tri-helix drivetrain. Conversely, consistent flat readings combined with level pitch and low encoder load allow the system to switch into flat-surface mode, engaging the retractable wheel subsystem. This strategy ensures that the robot remains responsive and stable even when lighting conditions compromise visual perception.

---

## 7. Key Engineering Decisions

Throughout the development of *Bose*, multiple engineering decisions were made to balance mechanical performance, sensor fidelity, power efficiency, cost constraints, and implementation complexity. This section highlights the key technical choices that shaped the robot’s architecture and capabilities. Decisions were driven not only by performance goals, but also by practical constraints such as budget, fabrication tools, available time, and the team's prior experience with embedded systems and physical prototyping.

The table below summarizes the most impactful decisions made during the design phase.

### 7.1 Summary of Major Design Decisions

| Category | Area | Decision | Justification |
|---|---|---|---|
| **Mechanical** | Mobility system | Tri-helix wheels for stair climbing | High step clearance, continuous motion, and unique geometry |
| | Flat-ground mode | Retractable wheels with lifting servos | Improved efficiency and reduced friction on level terrain |
| | Gear transmission | External 7:1 gear reduction after 157:1 gearbox | Essential to achieve sufficient torque for stair ascent |
| | Chassis material | Laser-cut 4 mm plywood | Lightweight, accessible, and compatible with fast prototyping methods |
| | Ground mode retrofit | Retractable wheels added after real-world testing | Response to tri-helix instability and inefficiency on flat terrain |
| **Electrical** | Motor supply | 14.4 V battery powering 9 V Maxon motors | Risk accepted to gain torque; required for successful climbing |
| | Dual regulators | Two step-down converters (5 V logic, 5–6 V actuators)| Isolated power domains to avoid brownouts and overloading sensitive devices |
| **Sensing & Logic** | SLAM approach | Monocular visual SLAM (ORB-based) | Low cost, no depth sensor required, real-time on embedded system |
| | LiDAR model | RPLIDAR C1 | 360º scanning, ROS support, and good range-to-cost ratio |
| **System** | Control board | Raspberry Pi 4B with ROS 2 Humble | Unified platform, good developer support, suitable for sensor integration |
| **Team & Scope** | Project scope | Chosen over other proposals for originality | One of the few concepts involving real physical-terrain navigation |
| | Student background | First physical build by Computer Engineering team | Added complexity and learning value despite lack of prior mechanical experience|

### 7.2 Design Trade-offs

Several non-trivial design decisions in *Bose* involved balancing performance, simplicity, fabrication feasibility, and cost. The most critical trade-offs made during development are summarized below.

**Chassis Material: Lightweight Wood vs. Structural Metals**  
Although metals like aluminum would have improved structural stiffness, the lack of CNC machining tools in the Open Labs limited viable options. Initially, full 3D printing was considered, but the weight and print time were prohibitive. Instead, 4 mm laser-cut plywood was chosen for its low density, ease of prototyping using the available CO₂ laser cutter, and sufficient mechanical performance for the use case.

**Mobility Mode: Tri-Helix Only vs. Hybrid Support System**  
The original concept involved using tri-helix wheels as the sole mode of locomotion. However, post-brainstorming analysis and early physical trials revealed significant instability and inefficiency on flat surfaces. A hybrid solution using retractable micro wheels improved performance on level terrain but introduced substantial complexity—requiring additional servos, motors, a second voltage regulator, new 3D-printed components, and terrain-detection logic.

**Perception Strategy: Monocular SLAM vs. Stereo or LiDAR-Only SLAM**  
The monocular visual SLAM module was selected due to the team's prior experience implementing ORB-based tracking in a Computer Vision course. At the outset, LiDAR was not available, and stereo cameras exceeded the project’s cost and processing constraints. The late-stage integration of LiDAR allowed obstacle detection to be added but did not replace the core SLAM pipeline.

**Motor Supply: Overdriving Maxon Motors for Torque**  
To achieve sufficient torque for stair ascent, 9 V Maxon motors were powered directly from a 14.4 V battery. Although this exceeded nominal voltage ratings, simultaneous operation of both motors appeared to distribute the electrical load. Empirically, no overheating or instability was observed during testing, and the trade-off was deemed acceptable.

**Frame Coupling: No Suspension or Damping**  
While soft mounting methods such as rubber isolators could have reduced vibration, the frame exhibited sufficient passive stability under load. Most structural elements were mechanically fastened using screws, and adhesive methods were deliberately avoided to maintain rigidity and allow disassembly.

**Architecture Simplicity: No Microcontroller Layer**  
A purely Raspberry Pi–based control system was adopted to simplify integration and reduce cost. While using dedicated microcontrollers for PWM generation or encoder processing might improve determinism, this was the team’s first embedded systems project. Centralizing logic in ROS 2 allowed for more rapid iteration and avoided the added wiring and firmware complexity.

### 7.3 Traceable Decisions File

To ensure design traceability and reproducibility throughout the development of *Bose*, we defined a structured documentation format in `docs/decisions.md`. This file is intended to serve as a curated log of major engineering decisions, each annotated with the context, alternatives considered, and the technical rationale behind the final choice.

Although this file remains a placeholder at the time of writing, it is part of our documentation roadmap and will be expanded to complement this section. It is intended to support future debugging, iteration, and potential replication by other student teams or research groups.

---

## 8. Experiments
To validate the stair-climbing and terrain-adaptive behavior of *Bose*, a series of functional tests were conducted under controlled indoor conditions. The experiments focused on mechanical performance, terrain-switching behavior, and visual SLAM stability.

### 8.1 Experimental Setup

All trials were performed at the **School of Engineering (Escola d'Enginyeria)** building of the **Universitat Autònoma de Barcelona (UAB)**. The robot was tested in both corridor environments and on a fixed staircase with standardized dimensions: each stair step measured **16 cm in height** and **30 cm in depth**.

Flat-ground trials were carried out on smooth floor tiles, while stair-climbing tests took place on a four-step flight located in a well-lit interior corridor. Video recordings were captured using a mobile phone, and a demo video is publicly available on YouTube to document the results.

### 8.2 Methodology

The evaluation scenarios included: (1) climbing stairs using the tri-helix mechanism, (2) transitioning to flat-ground drive mode using the retractable wheels, (3) terrain-type switching in reverse, and (4) partial autonomous navigation with SLAM running onboard.

Due to time constraints and integration complexity, **the experiments were conducted using manual control**, simulating autonomous transitions. While the SLAM and sensor-processing stack were functional, the full control pipeline was not deployed on-board at the time of testing.

Each scenario was executed once for validation. Success was defined by the robot’s ability to reach the top of the staircase or cross the flat test zone while maintaining **stability, smoothness, and traction** throughout the motion sequence.

### 8.3 Environments

All tests were performed in a clean, obstacle-free environment without pedestrian interference. Lighting remained consistent throughout trials, and no perceptual degradation due to shadows or reflections was observed.

One limitation encountered during stair ascent was the **slow climbing speed**, resulting from the use of an extremely high gear ratio (approx. **1100:1**, combining internal and external reductions). While this ensured sufficient torque, it substantially reduced the overall pace of the robot.

---

## 9. Results and Analysis

This section summarizes the observed performance, sensor behavior, and key outcomes of the test trials. Both quantitative data and qualitative feedback are presented to evaluate the robot's stair-climbing ability, terrain adaptation, and system stability.

### 9.1 Quantitative Performance

Despite being a prototype, *Bose* achieved complete stair-climbing sequences and terrain switching across several trials. The observed metrics are approximate but serve as a baseline for future comparison:

- **Stair climbing speed:** ~50 seconds to ascend a 4-step staircase (0.08 m/s vertical gain)
- **Flat ground velocity:** ~0.40 m/s using retractable wheels
- **Terrain mode transition time:** ~20 seconds (manual lift/lower cycle)
- **Total test duration per run:** ~5 minutes, including remote control and observation phases

### 9.2 Qualitative Observations

The robot successfully climbed all four steps without slipping, largely due to the patterned rubber-foam material applied at the tri-helix contact surfaces. Flat-ground navigation was also reliable and smooth, enabled by the retractable wheel mechanism. Transitions between modes, although not yet automatic, were triggered through keypresses and executed without error. The robot’s motion was smooth and stable, a known benefit of tri-helix kinematics, and no excessive vibration was detected.

Visual SLAM remained stable throughout the run. The robot maintained consistent pose estimation, and no major map drift or localization errors were observed. Stair detection using fused ultrasonic and camera input performed adequately to guide switching decisions, even though it was not yet integrated into an autonomous planner.

### 9.3 Limitations and Discussion

While the overall performance validated the mechanical and sensing approach, several limitations were encountered:

- **One of the servos failed** during early testing, emitting smoke and becoming non-functional. The cause was unclear, though a manufacturing defect is suspected.
- The **MD25 motor controller**, provided by the lab and known to be previously modified, sometimes exhibited erratic behavior. In repeated trials using the same control script, motor synchronization varied. Communication with the manufacturer (Robot Electronics) helped mitigate these issues, but some instability remained.
- During testing, **servo motors would occasionally actuate spontaneously**, despite no control signals being sent. These sporadic behaviors may be related to inconsistent voltage levels, I2C signal interference, or internal controller noise.
- **Remote control inputs occasionally lagged**, suggesting CPU or GPIO bottlenecks during high-load operation.
- **Component variance** was also noted. Even identical models from the same vendor (e.g., servos) sometimes behaved differently—likely a result of cost-driven manufacturing tolerances.

Some hardware documentation was missing or unavailable. The Maxon motor models were not searchable via part number, and the team contacted Maxon Spain directly to obtain datasheets for the motor, gearbox, and encoders. Similarly, manufacturer support was required to resolve undocumented behaviors in the MD25 controller.

Despite these issues, the robot consistently executed stair climbs, flat-terrain driving, and SLAM-based localization. The team maintained a proactive debugging approach, contacting vendors when documentation was insufficient and discussing critical failures with project supervisors as needed.

---

## 10. Discussion

The experimental outcomes of *Bose* highlight both the promise and the complexity of designing a hybrid-terrain, low-cost stair-climbing robot. The results validate the mechanical feasibility of tri-helix wheels for ascending architectural stairs, as well as the effectiveness of the retractable-wheel system for improving flat-ground locomotion. At the same time, the testing phase revealed multiple design trade-offs, unforeseen component limitations, and real-world integration challenges.

### 10.1 Result Interpretation

From a mechanical standpoint, the robot achieved its primary objective: climbing standard stairs autonomously in terms of actuation and structure. The tri-helix wheels proved to be a viable solution, with stable motion and adequate traction, especially after the addition of patterned rubber-foam surface material. The retractable wheel system, though added mid-project, demonstrated the value of adaptive mobility by enabling smoother and faster movement on flat surfaces.

Sensor performance was generally stable. The monocular SLAM pipeline tracked the robot’s pose with reasonable consistency, and fused readings from the ultrasonic sensor and camera were sufficient to detect stairs and trigger transitions manually. Though not fully autonomous, the system architecture and hardware demonstrated readiness for autonomous control in a future iteration.

### 10.2 Design Implications

The project confirmed that hybrid locomotion systems—when well-synchronized—can reduce energy consumption and improve terrain flexibility. However, it also became evident that such systems introduce additional mechanical complexity, wiring, and power management concerns. The decision to rely solely on the Raspberry Pi as the controller simplified integration, but also introduced latency and made I/O management more sensitive to load fluctuations.

The observed behavior of some components—such as undocumented servo failures, MD25 anomalies, and inconsistent vendor part performance—also highlighted the importance of sourcing quality parts and documenting all integration choices. Maintaining a structured engineering decision record (e.g., `decisions.md`) will be critical for future versions.

### 10.3 Constraints Encountered

Several constraints shaped the final design:

- **Fabrication tools:** Limited access to CNC or metalworking equipment necessitated the use of laser-cut plywood and 3D-printed components.
- **Prior knowledge:** As a first physical robotics project for the team (primarily computer engineering students), many mechanical and electronic decisions had to be learned from scratch.
- **Time limitations:** The project was completed within a single academic semester. This prevented full integration of autonomous navigation and reduced the number of test iterations.
- **Component availability:** Some key components (e.g., LiDAR) were provided late in the development cycle, forcing architectural changes mid-project. Additionally, **motor selection was a persistent bottleneck**—the team changed motors approximately four times due to lab stock constraints, which consumed time and required repeated mechanical adjustments.
- **Weight constraints:** Despite careful material selection and modular design, the robot’s final mass exceeded **5 kg**. This was not due to any single heavy component, but rather the accumulation of subsystems. It impacted actuation power and necessitated conservative speed and gear ratios.
- **Motor limitations:** The team used externally geared Maxon motors to increase torque, but an ideal solution would involve selecting motors with higher nominal torque from the outset. External gear stages increased mechanical complexity, alignment difficulty, and overall drivetrain length.

Despite these challenges, the project reached a functional prototype stage with confirmed stair-climbing and flat-terrain operation, a modular control stack, and a working perception system. The core design choices—tri-helix mobility, retractable support, and sensor fusion—remain validated, and provide a strong foundation for future iterations.

---

## 11. Future Work

While the current implementation of *Bose* validates its core design concepts, several opportunities exist for enhancement in future iterations. These improvements span hardware robustness, software autonomy, and broader use-case adaptability.

### 11.1 Hardware Improvements

Future prototypes would benefit from stronger actuators for the retractable support wheels. In particular, upgrading to high-torque servos and micro gearmotors would ensure faster terrain transitions and increased lifting reliability. Although the tri-helix wheels performed as intended and required no structural redesign, the overall system weight—currently over 5 kg—remains a limiting factor. Lightweight and rigid materials such as carbon fiber or composite laminates could be explored to reduce mass without compromising stability.

### 11.2 Software Extensions

At present, the robot operates under remote control with onboard perception modules active but not fully integrated. The logical next step is to complete the control pipeline for **autonomous terrain classification** and **mode switching**, triggered by sensor fusion rather than manual input. While the SLAM module is functional, enhancements such as multi-camera input and loop closure optimization could improve localization. However, any such improvements should remain **computationally lightweight**, as the system is expected to run on embedded hardware.

Adding core robotic software features—such as **path planning**, **real-time obstacle avoidance**, and **fail-safe behaviors** would significantly improve system robustness and autonomy.

### 11.3 Autonomous Capabilities

While waypoint navigation and multi-floor autonomy are not part of the current design, the system architecture could support these features with sufficient upgrades. Of particular interest is enabling autonomous multi-terrain mapping and pathfinding across stairs and flat regions using the combined visual and LiDAR pipeline.

Although this prototype was developed as part of an academic subject, the authors are now considering using the insights and architecture of *Bose* as the foundation for a full thesis project in the **Computer Engineering degree**. The experience gained has clarified many challenges and opportunities for developing more advanced autonomous stair-climbing robots within realistic constraints.

---

## 12. Conclusion
This paper presented Bose, a hybrid-terrain mobile robot capable of traversing standard architectural stairs and navigating flat indoor environments through an adaptive locomotion system. The design integrates low-cost mechanical components—namely, laser-cut tri-helix wheels and retractable support wheels—with a Raspberry Pi–based embedded architecture. Through extensive experimentation, we demonstrated that Bose could climb stairs up to 16 cm in height, transition to flat-ground mode, and maintain real-time localization using a visual SLAM pipeline complemented by LiDAR and ultrasonic sensing.

Our approach validated the potential of combining novel mechanical configurations with lightweight perception stacks in constrained academic settings. The tri-helix wheels offered smooth, stable, and continuous stair climbing, while the retractable-wheel subsystem significantly improved flat-ground performance. Despite limitations in actuation speed, component variability, and integration complexity, the robot met its core design objectives and provided a functional prototype within the constraints of time, cost, and infrastructure.

Importantly, this project served as the first full-scale physical build for the team—composed of computer engineering students with limited prior experience in mechanical or embedded system design. The steep learning curve associated with physical fabrication, motion control, and power electronics was met with rapid iteration, proactive problem-solving, and effective collaboration among team members and instructors. Notably, the robot concept was selected for its originality from among dozens of proposals, reinforcing the relevance and educational value of terrain-aware mobile robotics.

While Bose remains a prototype, the insights gained—including trade-offs between simplicity and functionality, the importance of material selection, and the challenges of real-world sensor fusion—lay a strong foundation for future iterations. Several team members are now considering the extension of this work into a dedicated undergraduate thesis project in the final year of the Computer Engineering degree, with the goal of achieving full autonomy, broader terrain generalization, and system miniaturization.

In sum, Bose demonstrates that practical, affordable, and intelligent stair-climbing robots are feasible within the scope of undergraduate academic research, and that a carefully engineered blend of mechanical design, perception, and control logic can unlock new frontiers in assistive and mobile robotics.

---

## Acknowledgment
The authors thank Prof. Fernando L. Vilariño Freire, Prof. Carlos G. Calvo, and Prof. Vernon S. Albayeros Duarte for supervision and guidance.  
This work was carried out in collaboration with the Open Labs of the School of Engineering (Laboratoris d’Innovació Oberta, UAB).

The authors also thank **Maxon Group Spain** and **Robot Electronics** for their prompt technical support regarding motor specifications and controller behavior during the development phase.

*Report version:* 27 Jun 2025.
---

## References

[1] R. R. Murphy, J. L. Burke, and M. D. Rogers, “Trial by Fire: Activities of the Rescue Robots at the World Trade Center from 11 to 21 September 2001,” *IEEE Robotics and Automation Magazine*, vol. 11, no. 3, pp. 50–61, Sep. 2004. doi:[10.1109/MRA.2004.1337826](https://doi.org/10.1109/MRA.2004.1337826)

[2] Endeavor Robotics, **“510 PackBot® Product Datasheet,”** Bedford, MA, USA, 2016. [Online]. Available: <https://web.archive.org/web/20140626225856/http://www.irobot.com/us/learn/defense/packbot.aspx>. Accessed: 20 Jun 2025.

[3] M. Hutter *et al.*, “ANYmal – A Highly Mobile and Dynamic Quadrupedal Robot,” in *Proceedings of the IEEE/RSJ International Conference on Intelligent Robots and Systems (IROS)*, Daejeon, South Korea, Oct. 2016, pp. 38–44. doi:[10.1109/IROS.2016.7758092](https://doi.org/10.1109/IROS.2016.7758092)

[4] G. Wu, L. Wu, H. Wang, W. Yang, Z. Wang, Z. Zhang, and T. Shen,  
“Design and Study of a Stair Climbing Robots with Two Wheels and a ‘4R+2P’ Pattern,” *Machines*, vol. 10, no. 8, Art. 631, Jul. 2022. doi:[10.3390/machines10080631](https://doi.org/10.3390/machines10080631)

[5] M. Eich, F. Grimminger, and F. Kirchner, “Adaptive Stair-Climbing Behaviour with a Hybrid Legged-Wheeled Robot,” in *Advances in Mobile Robotics: Proc. 11th Int. Conf. on Climbing and Walking Robots (CLAWAR 2008)*, Coimbra, Portugal, Sept. 2008. doi:[10.1142/9789812835772_0093](https://doi.org/10.1142/9789812835772_0093)

[6] B. D. Harrington and C. R. Voorhees, “The Challenges of Designing the Rocker-Bogie Suspension for the Mars Exploration Rover,” in *Proc. 37th Aerospace Mechanisms Symposium*, NASA Johnson Space Center, Houston, TX, USA, 19–21 May 2004. [Online]. Available: <https://ntrs.nasa.gov/api/citations/20040084284/downloads/20040084284.pdf>. Accessed: 20 Jun 2025.

[7] Y. Kim, J. Kim, H. S. Kim, and T. Seo, “Curved-Spoke Tri-Wheel Mechanism for Fast Stair-Climbing,” *IEEE Access*, vol. 7, pp. 173766–173773, 2019. doi:[10.1109/ACCESS.2019.2956163](https://doi.org/10.1109/ACCESS.2019.2956163)

[10] Youngsoo Kim, Jongwon Kim, Hwa Soo Kim, and TaeWon Seo, “Curved-Spoke Tri-Wheel Mechanism for Fast Stair-Climbing,” *IEEE Access*, vol. 7, pp. 173 766–173 773, Nov. 2019. doi:[10.1109/ACCESS.2019.2956163](https://doi.org/10.1109/ACCESS.2019.2956163)

---

## Appendix
- Circuit diagrams
- 3D model schematics
- Calibration data
- Full test logs

### Appendix A: Component Datasheets (External Links)

The following datasheets were referenced during the design and integration of the Bose robot. We provide official external links to ensure up-to-date and legal access. Local copies have not been included to respect distribution policies.

* [Raspberry Pi 4B - Brain of Robot](https://datasheets.raspberrypi.com/rpi4/raspberry-pi-4-product-brief.pdf), [Reduced Schematics](https://datasheets.raspberrypi.com/rpi4/raspberry-pi-4-reduced-schematics.pdf)

* [MD25 Dual Motor Controller - Helix Wheels and Encoders](https://www.robot-electronics.co.uk/htm/md25tech.htm)

* [L298N Dual Motor Controller - Retractable Wheel Motors](https://www.handsontec.com/dataspecs/L298N%20Motor%20Driver.pdf)

* [PCA9685 Servo Controller - 16 Channels](https://www.nxp.com/docs/en/data-sheet/PCA9685.pdf)

* [S13V30F5 Pololu DC Step-Up/Step-Down Regulator - 5V 3A](https://www.pololu.com/product/4082)

* [XL4015 DC Voltage Converter - Step-Down Regulator](https://solectroshop.com/en/convertidor-dc-step-down/647-xl4015-convertidor-voltimetro-dc-5a-75w-step-down-regulador-dc-lm2596-5905323239142.html), [LM2596 Datasheet](https://www.ti.com/lit/ds/symlink/lm2596.pdf)

* [3mm LEDs - Blue, Red, Green](https://www.make-it.ca/3mm-led-specifications/), [Farnell Datasheet](https://www.farnell.com/datasheets/1626756.pdf), [CETRONIC Datasheet](https://descargas.cetronic.es/WW03A3SRP4-N2.pdf)

* [RPLiDAR C1 - 360° Laser Range Scanner](https://bucket-download.slamtec.com/2d4664be9f9f5c748f3b608f2cf1862962b168eb/SLAMTEC_rplidar_datasheet_C1_v1.1_en.pdf), [User Manual](https://bucket-download.slamtec.com/9ab6ef03f6f98de7ee825a0c403cffc2a6bb5f22/SLAMTEC_rplidarkit_usermanual_C1_v1.1_en.pdf), [Protocol](https://bucket-download.slamtec.com/c5971f2703a8d014f3925694d798ea490a370efa/LR001_SLAMTEC_rplidar_S&C%20series_protocol_v2.8_en.pdf)

* [HC-SR04 Ultrasonic Distance Sensor](https://cdn.sparkfun.com/datasheets/Sensors/Proximity/HCSR04.pdf), [User Guide](https://www.elecfreaks.com/blog/post/hc-sr04-ultrasonic-module-user-guide.html)

* [Raspberry Pi Camera Module V2 - 8MP](https://www.raspberrypi.com/products/camera-module-v2/), [Documentation](https://www.raspberrypi.com/documentation/accessories/camera.html)

* [MPU6050 - 3-Axis Gyroscope & Accelerometer](https://cdn.sparkfun.com/datasheets/Components/General%20IC/PS-MPU-6000A.pdf), [Sunfounder Guide](https://docs.sunfounder.com/projects/ultimate-sensor-kit/en/latest/components_basic/05-component_mpu6050.html)

* [4700µF 16V Radial Electrolytic Capacitor - ELR47216](https://www.westfloridacomponents.com/mm5/graphics/Q04/NRWA472M16X31.pdf)

* [Double Switch - Circuit Disconnect](https://vishaworld.com/products/robotic-switch)

* [14.4V Battery - NASTIMA 2600mAh](https://www.amazon.com/-/es/NASTIMA-Reemplazo-bater%C3%ADa-2600mAh-compatible/dp/B089KGP8QH)

* [Maxon Motor 110055 - Tri-Helix Wheels](https://www.maxongroup.com/medias/sys_master/root/9399155818526/Cataloge-Page-EN-172.pdf)

* [Planetary Gearhead GP 16 A 157:1 - 118186](https://www.maxongroup.com/medias/sys_master/root/9406823858206/Cataloge-Page-EN-416.pdf)

* [Encoder MEnc 13 16 CPT - 110778](https://www.maxongroup.com/medias/sys_master/root/8831077548062/2018EN-407-408.pdf)

* [MG996R Servos - Retractable Wheels](https://components101.com/sites/default/files/component_datasheet/MG996R%20Datasheet.pdf)

* [150:1 Micro Metal Gearmotor HP 6V](https://www.pololu.com/file/0J1487/pololu-micro-metal-gearmotors-rev-6-1.pdf)

* [Push Button - Normally Open](https://components101.com/switches/push-button)

* [MH Level Converter - 5V to 3.3V](https://www.pololu.com/product/2595/resources)

> ⚠️ Note: The availability of external links is not guaranteed long-term. We recommend saving personal copies for archival or internal use.

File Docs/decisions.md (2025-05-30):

# Design & Engineering Decisions — Bose Stair-Climbing Robot

This document contains a curated list of key decisions that significantly impact the design, architecture, and performance of the Bose robot project.  
Each decision is recorded in a structured, unambiguous format to ensure traceability, technical clarity, and reproducibility of the project workflow.

---

## 2025-05-03 — Standardized Format for `decisions.md`

**Topic:** Documentation Structure  
**Decision:** Use a structured Markdown format for `decisions.md`, with one entry per decision including:  
- Topic  
- Date  
- Final decision  
- Technical rationale  
- Alternatives considered  
- Links to relevant logs or tests  

**Rationale:**  
During the first phase of the Bose robot project, multiple technical decisions were embedded inside daily progress logs (`/docs/logs/log_yyyy-mm-dd.md`). While those logs were valuable for tracking progress, they mixed together experiments, tests, and conclusions — making it difficult to identify and trace final, project-wide decisions.  
This format separates final decisions for clarity, traceability, and report integration.  

**Alternatives Considered:**  
- Embedding decisions in daily logs → too verbose and hard to trace  
- GitHub Issues → overkill for the scope of the project  
- Wiki page → lacks version control and log linkage  

**Chosen Format:**  
Every decision entry in this file must follow this structure:

```markdown
## YYYY-MM-DD — [Clear, Specific Title]

**Topic:** [Component, concept, or design area]  
**Decision:** [Final choice made — objective and unambiguous]  
**Rationale:**  
- [Technical reason 1]  
- [Technical reason 2]  
- [Constraints: cost, size, compatibility, power, etc.]  
**Alternatives Considered:**  
- [Alternative 1 — why rejected]  
- [Alternative 2 — why rejected]  
**Related Logs:** [`log_YYYY-MM-DD.md`](./logs/log_YYYY-MM-DD.md)
```

---

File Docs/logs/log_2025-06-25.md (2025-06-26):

# 🛠️ Daily Progress Log — 2025-06-25

## 👥 Team Members Present
- [x] Arun Sharma
- [x] Pau Domínguez Ruiz
- [x] Gerard Souto Eslava
- [x] Chengjie Peng Lin

## 🎯 What We Did Today

* Tested the remote control program for the robot
* Replaced existing gears with larger ones to increase torque
* Re-soldered some circuit elements that had come loose
* Laser-cut support pieces for the robot’s tail

## 💡 Decisions Made

| Topic | Decision | Why |
|---|---|---|
| Gear change | Switched to larger gears | To increase torque and improve movement strength |
| Circuit maintenance | Re-soldered loose connections | Ensure reliable operation and avoid signal loss  |
| Tail stability | Printed support pieces for tail | To keep the robot balanced during movement |

## 🧪 What We Tested

* Remote control response
* Performance with new gear ratio
* Electrical continuity after re-soldering

## 🔧 Problems Faced

* Laser cutter had to be stopped temporarily due to smoke extractor failure

## 📌 Next Steps

* Retest full system with improved gearing
* Mount tail support pieces and validate mechanical stability
* Continue refining remote control software

---

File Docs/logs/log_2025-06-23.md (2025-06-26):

# 🛠️ Daily Progress Log — 2025-06-24

## 👥 Team Members Present
- [x] Arun Sharma
- [x] Pau Domínguez Ruiz
- [x] Gerard Souto Eslava
- [x] Chengjie Peng Lin

## 🎯 What We Did Today

* Discussed performance issues: the robot is heavier than expected
* Held a meeting to organize the final presentation
* Identified that the axles are not powerful enough for reliable movement
* Began formalizing the circuit diagram for documentation

## 💡 Decisions Made

| Topic | Decision | Why |
|---|---|---|
| Presentation prep | Started outlining final presentation | To distribute tasks and define content structure  |
| Axle assessment | Acknowledge performance limitations | Motors/axles not strong enough for current weight |
| Circuit documentation | Begin formal circuit schematic | Required for final report and clarity |

## 🧪 What We Tested

* Communication between components

## 📌 Next Steps

* Complete circuit formalization
* Prepare slides and visual material for final presentation
* Consider summarizing hardware limitations in conclusions

---

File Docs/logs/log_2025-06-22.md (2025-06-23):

# 🛠️ Daily Progress Log — 2025-06-22

## 👥 Team Members Present
- [x] Arun Sharma
- [x] Pau Domínguez Ruiz
- [x] Gerard Souto Eslava
- [x] Chengjie Peng Lin

## 🎯 What We Did Today

* Covered the small flat-surface wheels with the same rubber as the main wheels to improve traction
* Mounted the camera and ultrasonic sensor onto the new front structure
* Closed the transparent box with all components inside
* Confirmed that the full circuitry remains correctly connected and functional

## 💡 Decisions Made

| Topic | Decision | Why |
|---|---|---|
| Wheel traction | Added rubber to small wheels | To ensure grip on flat surfaces |
| Sensor mounting | Fixed camera and ultrasound on new structure  | Final positioning for perception components |
| Enclosure | Closed transparent box | All elements now protected and enclosed properly  |

## 🧪 What We Tested

* Structural fit of new components
* Final electrical connections
* Grip of small wheels with new rubber layer

## 🔧 Problems Faced

* Robot is heavier than expected, which could affect mobility and climbing

## 📌 Next Steps

* Test robot movement with full weight
* Evaluate need for mechanical or motor adjustments due to increased weight

---

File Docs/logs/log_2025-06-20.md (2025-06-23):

# 🛠️ Daily Progress Log — 2025-06-20

## 👥 Team Members Present
- [x] Arun Sharma
- [x] Pau Domínguez Ruiz
- [x] Gerard Souto Eslava
- [x] Chengjie Peng Lin

## 🎯 What We Did Today

* Completed soldering of the full circuit board
* Verified the integration and communication between all components

## 💡 Decisions Made

| Topic | Decision | Why |
|---|---|---|
| Circuit integration | Finalized full system wiring and testing | Ensures all modules communicate correctly and are ready for testing |

## 🧪 What We Tested

* Power system distribution
* Communication between:
  - Motor drivers
  - Main controller
  - Sensors:
    - IMU
    - Encoders
    - 2D-LiDAR
* General circuit functionality

## 📌 Next Steps

* Begin system-level testing with software
* Monitor sensor readings

---

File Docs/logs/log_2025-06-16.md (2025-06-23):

# 🛠️ Daily Progress Log — 2025-06-16

## 👥 Team Members Present
- [ ] Arun Sharma
- [x] Pau Domínguez Ruiz
- [ ] Gerard Souto Eslava
- [ ] Chengjie Peng Lin

## 🎯 What We Did Today

* 3D printed support pieces to elevate all components from the robot base
* Included brackets, hinges, and other structural elements

## 💡 Decisions Made

| Topic | Decision | Why |
|---|---|---|
| Component layout  | Raise components above baseplate  | Improves overall stability |

## 🧪 What We Tested

* Fit and height of the new support pieces on the base

## 📌 Next Steps

* Assemble the box using the new supports and components
* Begin wiring and positioning internal electronics

---

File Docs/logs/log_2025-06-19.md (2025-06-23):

# 🛠️ Daily Progress Log — 2025-06-19

## 👥 Team Members Present
- [x] Arun Sharma
- [ ] Pau Domínguez Ruiz
- [ ] Gerard Souto Eslava
- [ ] Chengjie Peng Lin

## 🎯 What We Did Today

* Detected and fixed a mechanical misalignment on the right-side axle
* The axle was not properly aligned with the torque transmission, causing disconnection during operation

## 💡 Decisions Made

| Topic | Decision | Why |
|---|---|---|
| Right axle fix | Realigned axle with torque system | Prevents mechanical disconnection and instability |

## 🧪 What We Tested

* Axle alignment and stability after adjustment

## 📌 Next Steps

* Continue full assembly and integration of components
* Begin wiring and positioning internal electronics

---

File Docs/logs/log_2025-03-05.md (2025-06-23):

# 🛠️ Daily Progress Log — 2025-03-05

## 👥 Team Members Present
- [x] Arun Sharma
- [x] Pau Domínguez Ruiz
- [x] Gerard Souto Eslava
- [x] Chengjie Peng Lin

## 🎯 What We Did Today
- Initial meeting to explain the robot project.
- Ideation session to generate possible features and objectives.
- We agreed on the main concept: A robot capable of traversing different terrains and creating a 3D map of the area.

## 💡 Decisions Made
| Topic | Decision | Why |
|---|---|---|
| Main objective | Robot with versatile mobility and 3D mapping	 | Meets the project requirements for exploration and map generation |
| Types of terrain to cover	 | Flat ground, sand, and rocky terrain	 | Allows testing of suspension and traction systems under different conditions |
| Mapping tools	| LiDAR sensor + RGB-D camera	| Combines high-precision distance data (LiDAR) with color/texture data (RGB-D) |

## 🧪 What We Tested
- Brainstormed chassis ideas and wheel types.
- Mentally simulated the data flow from sensor to SLAM algorithm.

## 🔧 Problems Faced
- A wide range of initial ideas led to some difficulty prioritizing features.
- Uncertainty about the best way to integrate the LiDAR sensor with our chosen platform.

## 📌 Next Steps
- Define technical requirements for suspension and wheels.
- Select a specific LiDAR module (range, accuracy, interface).
- Prepare a rough mechanical design sketch in CAD.

---

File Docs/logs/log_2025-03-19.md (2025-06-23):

# 🛠️ Daily Progress Log — 2025-03-19

## 👥 Team Members Present
- [x] Arun Sharma
- [x] Pau Domínguez Ruiz
- [x] Gerard Souto Eslava
- [x] Chengjie Peng Lin

## 🎯 What We Did Today
- Original rover idea was rejected due to high cost and simplicity
- Brainstormed alternative ideas and settled on a stair-climbing robot for rough terrains
- Explored different climbing mechanisms (tank-like, 6-wheel, step-lifting, etc.)
- Decided on a 2 tri-helix stair-climbing robot concept
- Identified the need for custom dimensions and extremely high-torque motors
- Sent a first version of the electrical components list
- Visited UAB Open Labs to explore available resources and services

## 💡 Decisions Made
| Topic | Decision | Why |
|---|---|---|
| Locomotion mechanism | Two helical (spiral) wheels paired with a rigid base | Helical wheels provide continuous contact on stair edges, enabling smooth vertical climbs |
| Motor driver | Dual DC motor driver DRV8833 | Compact, efficient, and fully compatible with our chosen micro metal gear motors |
| Controller | Raspberry Pi 4 Model B (4 GB RAM) | Sufficient processing power for image capture, SLAM, and motion control algorithms |
| Vision sensor | Raspberry Pi Camera v2 (8 MP) | High-resolution images for stair detection and mapping |
| Drive motors | Micro Metal LP motors with 250:1 gearboxes | High torque output needed to drive helical wheels up inclines |
| Power source | LiPo 2S battery (1100 mAh, 7.4 V, 120C) | High discharge rate for sustained motor operation |
| Voltage regulation | S13V30F5 5 V DC–DC converter (3 A) | Provides stable 5 V rail for Raspberry Pi and sensors |
| Obstacle detection | HC-SR04 ultrasonic distance sensor | Reliable short-range obstacle/stair edge detection |
| Inertial sensing | MPU-6050 3-axis gyroscope & triaxial accelerometer (I²C, 3–5 V) | Measures pitch/roll to assist in balance control when transitioning between stair steps |

## 🧪 What We Tested
- Reviewed mechanical feasibility of mounting helical wheels on the existing chassis.  
- Verified compatibility of DRV8833 driver with Micro Metal LP motors in simulation.

## 🔧 Problems Faced
- Ensuring sufficient ground clearance for the helical wheels during flat-terrain traversal.  
- Balancing weight distribution to prevent front or rear tipping when climbing stairs.  

## 📌 Next Steps
1. Design and 3D-print a mounting bracket for the helical wheels and motor assemblies.  
2. Prototype the base frame in CAD, incorporating battery and electronics compartments.  
3. Write and test low-level motor control routines for synchronized helical-wheel rotation.  
4. Plan initial physical trials on a demo stair module (3–5 steps).

---

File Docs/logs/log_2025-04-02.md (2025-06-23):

# 🛠️ Daily Progress Log — 2025-04-02

## 👥 Team Members Present
- [x] Arun Sharma
- [x] Pau Domínguez Ruiz
- [x] Gerard Souto Eslava
- [x] Chengjie Peng Lin

## 🎯 What We Did Today

* Created an updated list of components for the robot, including new and modified items
* Designed and submitted a basic hardware diagram showing the physical layout of the robot
* Drafted and submitted a simple software flowchart to describe initial logic structure

## 💡 Decisions Made

| Topic | Decision | Why |
| --- | --- | --- |
| Component selection  | Updated list with revised and new components | Improved clarity on hardware needs |
| Design documentation | Submitted basic hardware + software diagrams | To guide future integration and development |

## 🧪 What We Tested

* No physical tests conducted — focus was on planning and documentation

## 🔧 Problems Faced

* Still in early planning; no major technical issues at this stage

## 📌 Next Steps

* Wait for delivery of components
* Prepare for physical integration in the next session
* Begin drafting early test scenarios for sensors and motors

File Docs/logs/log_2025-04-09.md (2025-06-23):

# 🛠️ Daily Progress Log — 2025-04-09

## 👥 Team Members Present
- [x] Arun Sharma
- [x] Pau Domínguez Ruiz
- [x] Gerard Souto Eslava
- [x] Chengjie Peng Lin

## 🎯 What We Did Today
- Laser cutting of the initial prototype of the tri-helix wheel on a single wood sheet.  
- Printed a one-layer wheel prototype to validate dimensions.  
- Tested the single-layer prototype on actual stairs to assess the fit and traction of only one layer of wood.

## 💡 Decisions Made
| Topic | Decision | Why |
|---|---|---|
| Manufacturing method | Use laser-cut wood lamina instead of 3D printing | Wheel diameter is quite large, so the laser cutting on sheet stock is faster, less expensive for out universoty, and reduces material waste |
| Future wheel design | Laminate multiple wood sheets by gluing together | Could produce a lighter and stronger structure. |

## 🧪 What We Tested
- Staircase traversal performance with the single-layer prototype.  
- Dimensional accuracy of laser-cut lamina compared to CAD model.

## 🔧 Problems Faced
- We ran into some issues when exporting the 3D model of the wheel — the format wasn’t compatible with the laser cutter software, so we had to re-export and adjust several times.

## 📌 Next Steps
- Start working on the design of the **final wheel model** now that the dimensions are validated.  
- Create updated file for the **layered version of the tri-helix wheel**, splitting it into multiple parts for easier assembly.  
- Design and include the **three alignment triangles** that will help the wheel match the stair edges correctly.

---

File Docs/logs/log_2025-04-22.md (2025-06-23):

# 🛠️ Daily Progress Log — 2025-04-22

## 👥 Team Members Present
- [x] Arun Sharma
- [x] Pau Domínguez Ruiz
- [x] Gerard Souto Eslava
- [x] Chengjie Peng Lin

## 🎯 What We Did Today
- 3D printed several small structural parts related to component stability:  
  - Battery bracket  
  - Camera handle  
  - Motor cases  
  - Raspberry Pi case  
  - Ultrasonic sensor mount  
- Laser cut **two new tri-helix wheels**, which are intended to be the final design version.

## 💡 Decisions Made
| Topic | Decision | Why |
|---|---|---|
| Topic | Decision | Why |
|--------------------|----------------------------------------------|----------------------------------------------------------------------|
| Structural mounts  | 3D print small component holders | Keeps elements securely in place |
| Wheel design | Laser cut final version of tri-helix wheels  | We refined the previous design by adding holes to reduce weight and compensate for the thickness added by layering multiple wooden sheets, aiming for better traction and lighter wheels |

## 🧪 What We Tested
- Fit and placement of the 3D printed structural components on the chassis.  
- Assembly of the two final laser-cut tri-helix wheels.

## 🔧 Problems Faced
- All the laser-cut parts required manual sanding to remove small imperfections and ensure proper fit during assembly.

## 📌 Next Steps
- Mount the new tri-helix wheels onto the motors and test it manually in stairs.
- Evaluate motors strenght with the new wheels.  

---

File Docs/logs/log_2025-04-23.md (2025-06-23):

# 🛠️ Daily Progress Log — 2025-04-23

## 👥 Team Members Present
- [x] Arun Sharma
- [x] Pau Domínguez Ruiz
- [x] Gerard Souto Eslava
- [x] Chengjie Peng Lin

## 🎯 What We Did Today

* Mounted the robot hardware for the first time
* Conducted a simple test using an ultrasonic sensor to explore software-hardware integration
* Received most of the ordered components
* Selected motors based on physical resistance (couldn’t move shaft by hand)

## 💡 Decisions Made

| Topic | Decision | Why |
| --- | --- | --- |
| Motor choice | Chose the motor with immovable shaft | Assumed it had high gear ratio and torque |
| Power supply | Used 8×1.2V NiMH cells instead of LiPo | Ordered LiPo battery didn’t arrive |

## 🧪 What We Tested

* Integration of ultrasonic sensor with software
* Motor torque evaluation (manually, by feel)

## 🔧 Problems Faced

* Some components (e.g., LiPo battery) didn’t arrive
* Gear ratio of motors was unknown at the time (later estimated \~150:1)

## 📌 Next Steps

* Proceed with system integration using received components
* Replace temporary power supply with proper LiPo when available
* Begin planning for mobility and torque testing in upcoming sessions

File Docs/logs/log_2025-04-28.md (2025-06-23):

# 🛠️ Daily Progress Log — 2025-04-28

## 👥 Team Members Present
- [x] Arun Sharma
- [x] Pau Domínguez Ruiz
- [x] Gerard Souto Eslava
- [x] Chengjie Peng Lin

## 🎯 What We Did Today
- 3D printed a limited number of parts to save time:  
  - Top part of the battery case  
  - Back side of the motor case  
  - Brackets for securing components inside the electronics box  
  - Small spacers to create gaps between stacked components  
- Just before the power outage, we completed a **laser cutting session** to make a simple acrylic box that will contain all electronic components in a clean and elegant way.

## 💡 Decisions Made
| Topic | Decision | Why |
|---|---|---|
| Printing time | Only printed essential structural parts | To avoid long print times and focus on the most needed pieces |
| Electronics box | Laser cut from transparent acrylic | Provides a clean, minimal look while keeping all wiring organized |

## 🧪 What We Tested
- Fit of the printed brackets and spacers inside the transparent box.  
- Assembly of the laser-cut acrylic enclosure.

## 🔧 Problems Faced
- A power blackout in Spain interrupted the 3D printing job midway.  
- Fortunately, the printers resumed correctly when power returned, and the prints were completed without damage.

## 📌 Next Steps
- Mount all electronic components inside the new acrylic box.  
- Finish printing the remaining parts of the battery and motor case.  
- Begin organizing and routing cables neatly inside the enclosure.  

---

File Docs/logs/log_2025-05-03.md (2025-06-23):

# 🛠️ Daily Progress Log — 2025-05-03

## 👥 Team Members Present
- [x] Arun Sharma
- [x] Pau Domínguez Ruiz
- [x] Gerard Souto Eslava
- [x] Chengjie Peng Lin

## 🎯 What We Did Today
- We structured the entire project repository for clarity and scalability.
- Created a clear directory layout for:
  - `hardware/` (all 3D models, laser cuts, circuit designs)
  - `software/` (motion, sensors, SLAM, utility scripts)
  - `docs/` (daily logs, decision table, final report)
  - `media/` (photos, renders, GIFs)
- Established a consistent format for daily logs and decision logs.
- Decided to document every key technical and design decision made.

## 💡 Decisions Made
| Topic | Decision | Why |
|---|---|---|
| Repository layout  | Use clean folder structure with hardware/software/docs | Makes code, design files, and documentation easy to navigate |
| Logs | Daily Markdown logs + decision table | Helps track progress, justifies choices, supports final report |
| License | Use MIT License | Open source, easy reuse, clear team attribution |
| Documentation style| Markdown + GitHub + final scientific report | Readable, lightweight, easy to version |

## 🔧 Problems Faced
- We had many STL files, circuit images, and code scattered around.
- Decision justifications were in team chat only — hard to trace.
- No proper logging of progress or rationale up to this point.

## 📌 Next Steps
- Begin regular daily logs after each work session or milestone.
- Migrate and sort old files into the new folder structure.
- Push the full structured repo to GitHub with README and LICENSE.

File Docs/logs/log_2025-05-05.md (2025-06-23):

# 🛠️ Daily Progress Log — 2025-05-05

## 👥 Team Members Present
- [x] Arun Sharma
- [x] Pau Domínguez Ruiz
- [x] Gerard Souto Eslava
- [x] Chengjie Peng Lin

## 🎯 What We Did Today
- 3D printed:  
  - A new and improved camera stand with increased height and better stability  
  - The bottom part of the battery case  
  - These parts ended up being **double-colored** due to a filament runout mid-print, but they are still functional  
- Laser cut the **wooden base of the robot**, including an engraved dedication recognizing all team members, our teachers, and the support of the Open Labs.  
- Planned to cut the tail section of the robot, but couldn’t proceed due to **time constraints** and issues with the lab computer.

## 💡 Decisions Made
| Topic | Decision | Why |
|---|---|---|
| Camera support | Reprint with taller, more stable design | The original was too short and unstable for the actual camera usage |
| Robot base | Engrave credits on wooden base | A meaningful touch to highlight collaboration and contributors |

## 🧪 What We Tested
- Fit and balance of the new camera stand  
- Stability of the wooden base with the current component layout

## 🔧 Problems Faced
- The filament ran out mid-print, resulting in a color change on the printed parts  
- Couldn’t cut the robot’s tail due to limited lab time and a malfunctioning lab computer

## 📌 Next Steps
- Reschedule the laser cutting of the robot’s tail piece  
- Assemble all printed and laser-cut parts together on the robot base  
- Test overall structural stability and the new base and camera stand  

---

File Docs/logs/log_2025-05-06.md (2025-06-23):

# 🛠️ Daily Progress Log — 2025-05-06

## 👥 Team Members Present
- [x] Arun Sharma
- [x] Pau Domínguez Ruiz
- [x] Gerard Souto Eslava
- [x] Chengjie Peng Lin

## 🎯 What We Did Today
- Laser cut the **tail of the robot**.  
- Spent the remaining time **cleaning the support material** from the 3D printed parts from the previous day.

## 💡 Decisions Made
| Topic | Decision | Why |
|---|---|---|
| Task planning | Use extra time for cleanup tasks | To keep all parts ready for final assembly |

## 🧪 What We Tested
- Not applicable — today focused on finalizing parts.

## 🔧 Problems Faced
- No problems today.

## 📌 Next Steps
- Begin final assembly of the robot with all laser-cut and printed parts.

---

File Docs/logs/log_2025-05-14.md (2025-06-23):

# 🛠️ Daily Progress Log — 2025-05-14

## 👥 Team Members Present
- [x] Arun Sharma
- [x] Pau Domínguez Ruiz
- [x] Gerard Souto Eslava
- [x] Chengjie Peng Lin

## 🎯 What We Did Today

* Assembled the first physical version of the robot (MVP)
* Tested initial motors — found them too weak due to low torque
* Rejected a 12V motor offered by the lab (no gear ratio)
* Planned to test new motors before next session

## 💡 Decisions Made

| Topic | Decision | Why |
| --- | --- | --- |
| Motor selection | Rejected 12V motor with no gearbox | No gear ratio = insufficient torque |
| Gear ratio strategy | Use Maxon motors with 157:1 gear ratio (12V) | Higher torque, possibly suitable for climbing stairs |

## 🧪 What We Tested

* Original MVP with basic motors
* 12V motors with 30:1 gear ratio (failed test)
* Received Maxon 12V motors with 157:1 gear ratio (not yet tested)

## 🔧 Problems Faced

* Initial motors lacked the necessary torque
* 30:1 gear ratio motors were also too weak
* No suitable motor options from lab stock until teacher’s help

## 📌 Next Steps

* Test Maxon motors (157:1) provided by the teacher
* Evaluate climbing performance with new motors
* Integrate the 14V battery into the system
* Prepare for potential final integration in the following session

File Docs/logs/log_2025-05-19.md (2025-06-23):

# 🛠️ Daily Progress Log — 2025-05-19

## 👥 Team Members Present
- [x] Pau Domínguez Ruiz
- [x] Gerard Souto Eslava
- [x] Chengjie Peng Lin

## 🎯 What We Did Today
- 3D printed several components: brackets for the transparent box, initial prototype of the robot lifters, and servo brackets.
- Laser cut two small wooden pieces to stabilize the robot's tail, which was moving excessively during testing.

## 💡 Decisions Made
| Topic | Decision | Why |
|---|---|---|
| Transparent box mounting | Redesigned brackets to be sturdier | Original ones broke during installation |
| Tail stability support  | Added wooden supports via laser cut | Tail was too loose and affected balance |

## 🧪 What We Tested
- Fit and strength of the newly printed brackets.
- Effectiveness of the wooden tail supports during basic movement.

## 🔧 Problems Faced
- The first set of printed brackets cracked when attaching the transparent box.
- The tail was too unstable, requiring reinforcement.

## 📌 Next Steps
- Ensure all structural elements are securely mounted for the next movement test.

---

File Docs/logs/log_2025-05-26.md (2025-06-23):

# 🛠️ Daily Progress Log — 2025-05-26

## 👥 Team Members Present
- [x] Arun Sharma
- [x] Pau Domínguez Ruiz
- [x] Gerard Souto Eslava
- [x] Chengjie Peng Lin

## 🎯 What We Did Today
- Printed a new 3D camera stand with reduced height, since the previous version was too tall.
- Printed what is likely the final version of the lifters.
- Printed new motor cases, but they turned out too narrow due to lack of datasheet measurements.
- Attempted to expand motor cases using heat in the oven, but results were uneven — will reprint.
- Printed servo stabilizers to prevent unwanted movement.
- Printed two small wheels to allow the robot to move on flat surfaces.

## 💡 Decisions Made
| Topic | Decision | Why |
|---|---|---|
| Camera stand height | Lowered the camera mount | Previous version placed the camera too high |
| Motor case design | Reprint with corrected measurements | Current version is too narrow and deformed after heating |
| Servo stabilization | Added printed brackets | Prevents servos from shifting during movement |

## 🧪 What We Tested
- Fit and alignment of the new camera stand.
- Fit of the motor cases (unsuccessful).
- Stability improvements from the servo brackets.

## 🔧 Problems Faced
- Lack of motor datasheet caused inaccurate case sizing.
- Heat-expansion workaround for motor cases didn’t work well — parts warped and became asymmetric.

## 📌 Next Steps
- Reprint the motor cases with updated dimensions based on manual measurements.
- Begin mounting and aligning all components for first full movement test.
- Evaluate performance of small wheels on flat surfaces.

---

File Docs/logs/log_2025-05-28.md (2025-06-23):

# 🛠️ Daily Progress Log — 2025-05-28

## 👥 Team Members Present
- [x] Arun Sharma
- [x] Pau Domínguez Ruiz
- [x] Gerard Souto Eslava
- [x] Chengjie Peng Lin

## 🎯 What We Did Today

* Concluded the last compulsory lab session (Session 6)
* Tested Maxon motors; found them too weak for climbing or flat surface movement
* Tried alternative motor from the lab, but it burned out at the stalling limit
* Received a 2D-LiDAR sensor due to limitations of camera-only navigation
* (Open Lab) Planned to laser cut a new lightweight transparent box, but canceled the task after confirming that the robot was not capable of climbing
* (Open Lab) Laser cut two small wooden parts to help the servos stay firm at their final positions without overexerting force

## 💡 Decisions Made

| Topic | Decision | Why |
| --- | --- | --- |
| Motor strategy | Move focus to software if motors fail | Current motors are inadequate; need higher torque |
| Sensor suite | Add 2D-LiDAR to setup | Camera-only navigation was too unreliable |
| Transparent box | Cancelled redesign and cutting | Robot mobility is still not resolved; major changes needed |
| Servo support stops  | Added wooden mechanical end-stops | Compensates for weak servos provided in the project |

## 🧪 What We Tested

* Maxon motors on stairs and flat surface
* Alternative lab-provided motor
* Initial integration of 2D-LiDAR
* (Open Lab) Passive servo support using laser-cut wood pieces

## 🔧 Problems Faced

* Maxon motors couldn't generate enough torque
* Lab motor burned out during testing
* General demotivation due to repeated hardware failures

## 📌 Next Steps

* Focus on developing simple software fallback solution
* Attend upcoming optional lab sessions to test other motor options
* If new motors allow climbing, continue with full software pipeline; otherwise, limit scope

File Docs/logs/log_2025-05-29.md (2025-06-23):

# 🛠️ Daily Progress Log — 2025-05-29

## 👥 Team Members Present
- [x] Arun Sharma
- [x] Pau Domínguez Ruiz
- [x] Gerard Souto Eslava
- [x] Chengjie Peng Lin

## 🎯 What We Did Today
1. Reviewed the current motor-to-wheel setup and identified structural limitations.  
2. Decided to add **gears** between the motors and the wheels to increase the torque and improve stair-climbing performance.  
3. Considered the possibility of using **servo motors**, but concluded they were not suitable for the torque and continuous rotation needed for stair climbing.

## 💡 Decisions Made

| Topic | Decision | Why |
|---|---|---|
| Power transmission  | Add a gear system between motors and wheels | Helps multiply torque and reduce the load directly on the motors |
| Motor type | Stick with DC motors + gears instead of switching to servos | Servos don’t provide continuous rotation or sufficient power for stair climbing tasks |

## 🧪 What We Tested
- Evaluated current torque limitations when the robot is under stair-climbing load.  
- Explored mechanical configurations for fitting a gear system onto the existing chassis.

## 🔧 Problems Faced
- Space constraints on the chassis for mounting additional gears.  
- Complexity in aligning gears properly to avoid slippage or efficiency loss.

## 📌 Next Steps
1. Design and 3D-print gear mounts and adapters to fit between motors and wheels.  
2. Test the new geared system under load to confirm improved climbing performance.  
3. Rebalance the chassis layout if needed to accommodate new mechanical components.  
4. Final preparation for the presentation, ensuring both hardware and software run smoothly.

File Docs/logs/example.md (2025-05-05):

# 🛠️ Daily Progress Log — 2024-05-06

## 👥 Team Members Present
- [ ] Arun
- [x] Domínguez
- [x] Souto
- [x] Chen

## 🎯 What We Did Today
- Did **X thing**
- Finalized **X**

## 💡 Decisions Made
| Topic | Decision | Why |
|---|---|---|
| Sensor 1 | sdvgrsebrtgntbrgnb | bfgbfrstbhnwtgrntn |
| Sensor 2 | bfdbrthwbarwbhtgng | efdvbarwhywtathfbfrt |

## 🧪 What We Tested
- thing 1
- thing 2

## 🔧 Problems Faced
- Some confusion about...
- STL import, ...

## 📌 Next Steps
- Print the penguin and frog
- Mount MPU-6050 physically and start reading values
- Set up basic SLAM framework on the Pi

---

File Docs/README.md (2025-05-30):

# 🧾 Bose Robot Documentation

This folder contains all documentation related to the development of the **Bose** stair-climbing robot.

## Structure

- `/logs/` — Daily progress logs (one per working day).
- `decisions.md` — A running summary of all major technical and design decisions.
- `final_report.md` — The final scientific-style report.

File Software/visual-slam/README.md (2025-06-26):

## Visual SLAM Python Implementation

Este proyecto se centra en la implementación de un sistema de Visual SLAM monocular. Es una primera aproximacion del visual slam para el proyectio de RLP para el robot BOSE, inspirado en ORB-SLAM2, utilizando una cámara para extraer características, rastrear la trayectoria de la cámara y generar un mapa 3D del entorno.

### Estructura del proyecto

```
visual-slam/
├── configs/               # Parámetros de cámara y SLAM (ORB, matcher, tracking, mapping, I/O)
│   └── monocular.yaml     # Configuración principal (intrínsecos, distorsión, thresholds, rutas)
│
├── data/                  # Datos de entrada y salida
│   └── hospital_video.mp4 # Vídeo monocular de prueba para la ejecución del SLAM
│
├── src/
│   ├── orbslam2/          # Implementación del núcleo SLAM
│   │   ├── __init__.py    # Inicialización del paquete y versión
│   │   ├── extractor.py   # Extracción de características ORB
│   │   ├── initializer.py # Inicialización del mapa (primeros dos fotogramas)
│   │   ├── matcher.py     # Emparejamiento de descriptores ORB
│   │   ├── tracker.py     # Lógica de tracking frame-a-frame y pose estimation
│   │   ├── local_mapper.py# Creación y refinamiento de keyframes y puntos de mapa
│   │   └── utils.py       # Funciones auxiliares (config, calibración, triangulación)
│   └── tests/             # Tests unitarios con pytest
│       ├── test_matcher.py      # Validación de emparejamiento de descriptores
│       └── test_orb_extractor.py# Pruebas de extracción de características ORB
│
└── README.md              # Guía de uso, instalación y ejemplos de ejecución
```

### Descripción general

* **Visual SLAM**: Procesa un vídeo monocular para extraer puntos clave ORB, seguirlos en cada fotograma y estimar la posición de la cámara.
* **Mapeo 3D**: A partir de los fotogramas extraídos, triangula puntos y construye una nube de puntos 3D que se exporta en formato PLY.
* **Modularidad**: Cada componente (extracción, inicialización, matching, tracking, mapeo) está organizado en módulos claros para facilitar mantenimiento y extensión.

### Instalación

1. Clonar el repositorio:

   ```bash
   git clone https://github.com/tu_usuario/visual-slam.git
   cd visual-slam
   ```
2. Crear un entorno virtual y activar
3. Instalar dependencias

### Uso

1. Ajustar parámetros en `configs/monocular.yaml` (intrínsecos, thresholds, rutas de I/O).
2. Ejecutar el script principal (por ejemplo, `run_slam.py`):

   ```bash
   python run_slam.py --config configs/monocular.yaml
   ```
3. Visualizar el mapa:

   * El mapa 3D se guardará en `data/map.ply`.
   * Opcionalmente, utilizar un visor de nubes de puntos para inspeccionar el resultado.

---

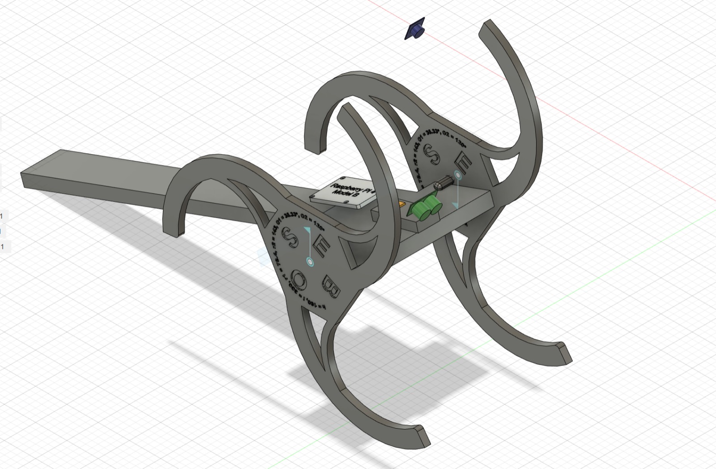
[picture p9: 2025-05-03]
Media/InitialDesign.jpg

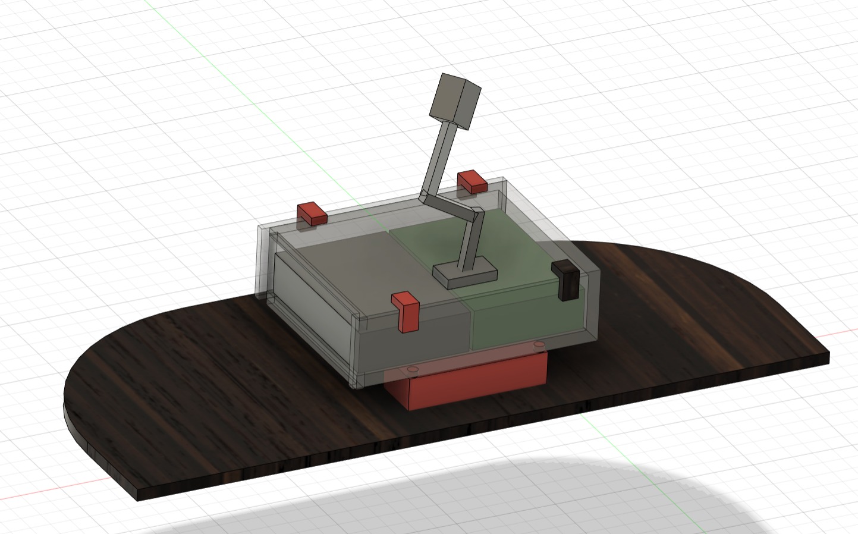
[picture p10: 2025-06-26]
Media/3D placa.jpeg

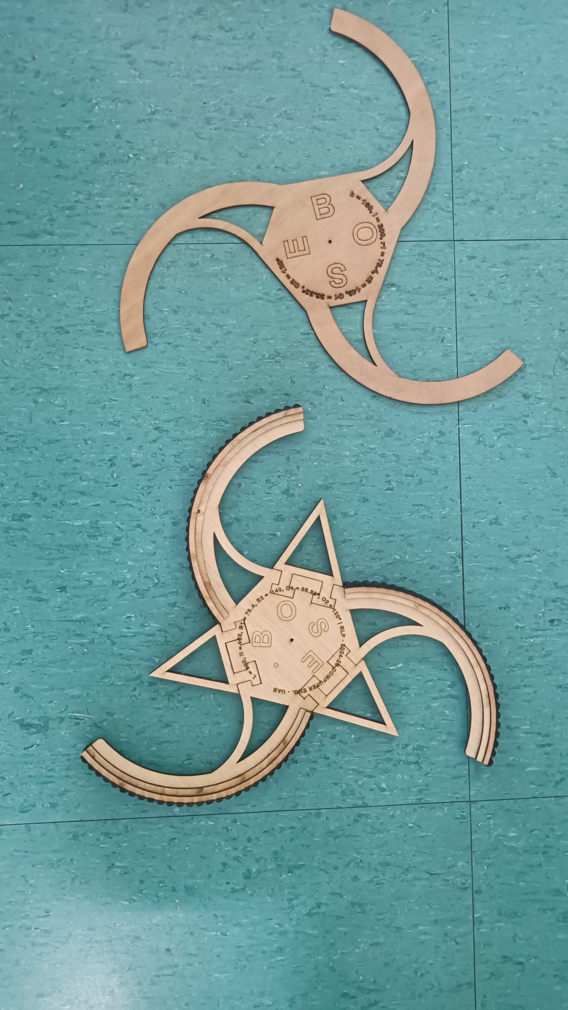
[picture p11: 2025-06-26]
Media/Wheels Impression.jpeg

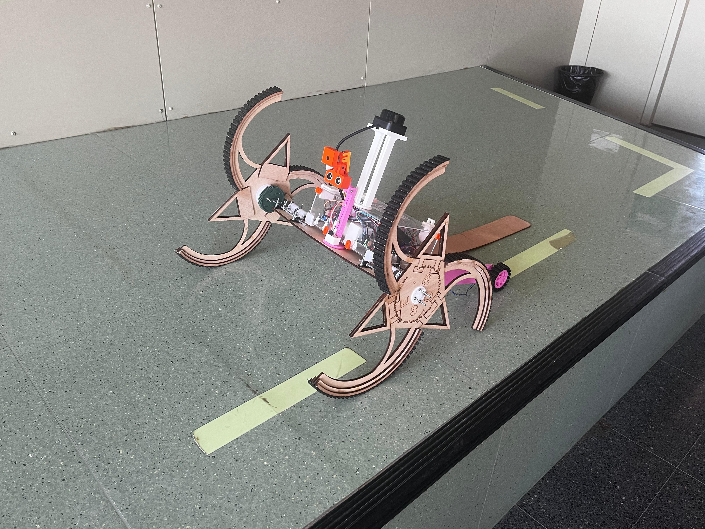
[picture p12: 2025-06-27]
Media/BoseOnFlat.jpg

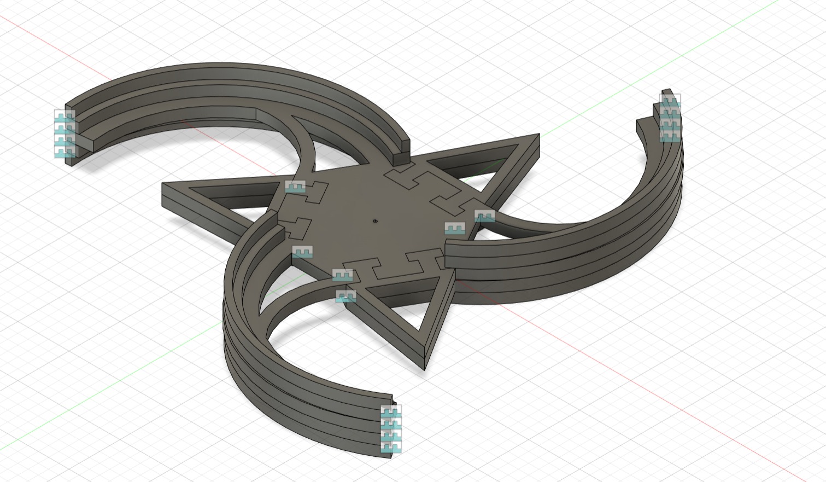
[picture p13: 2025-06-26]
Media/wheel 3d prototype.jpeg

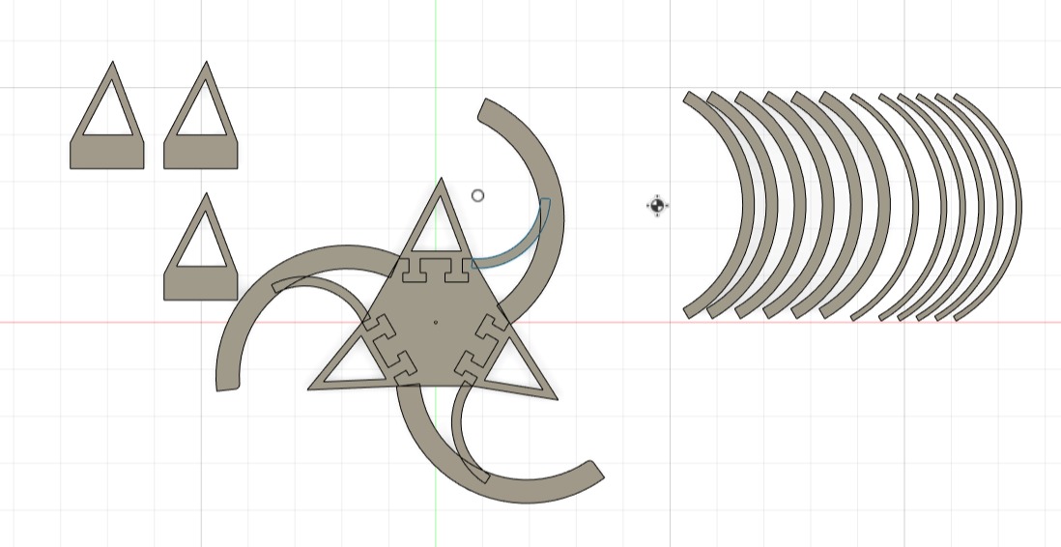
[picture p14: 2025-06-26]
Media/Wheel 3d prototype v1.jpeg

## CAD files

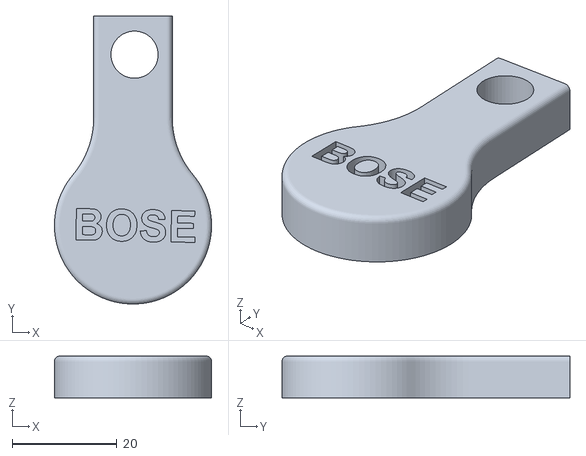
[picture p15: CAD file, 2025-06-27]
Hardware/STL/LockMain.stl
30.0 x 55.0 x 8.00

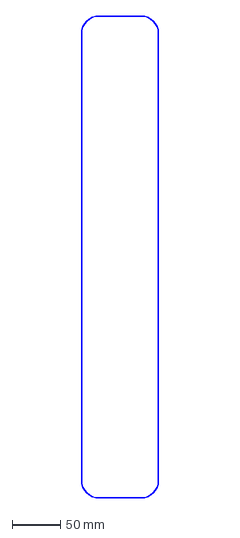
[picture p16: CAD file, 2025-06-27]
Hardware/DXF/cola.dxf
79.6 x 499.6 mm

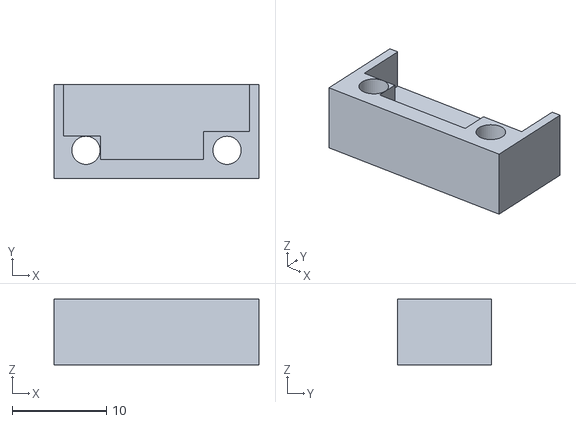
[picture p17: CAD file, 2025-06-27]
Hardware/STL/GyroscopeTop.stl
21.8 x 10.0 x 7.00

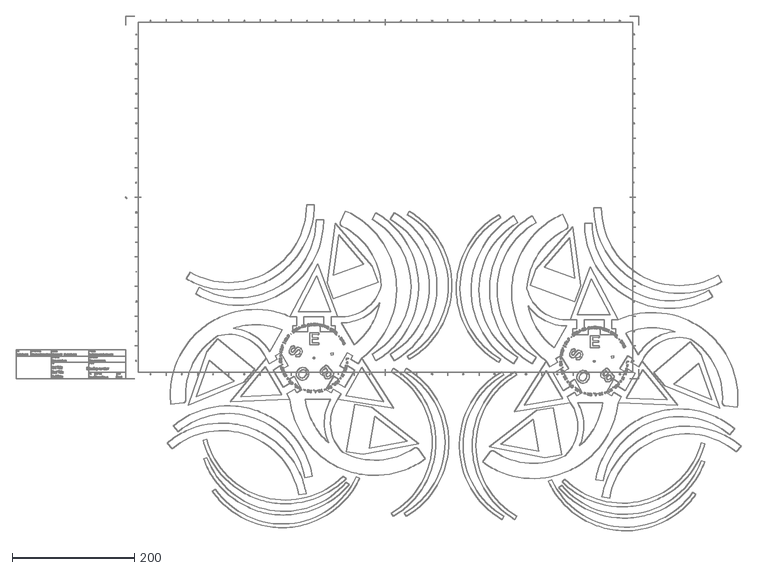
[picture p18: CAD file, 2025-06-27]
Hardware/DXF/WoodWheelV1.dxf
1188.5 x 843.5

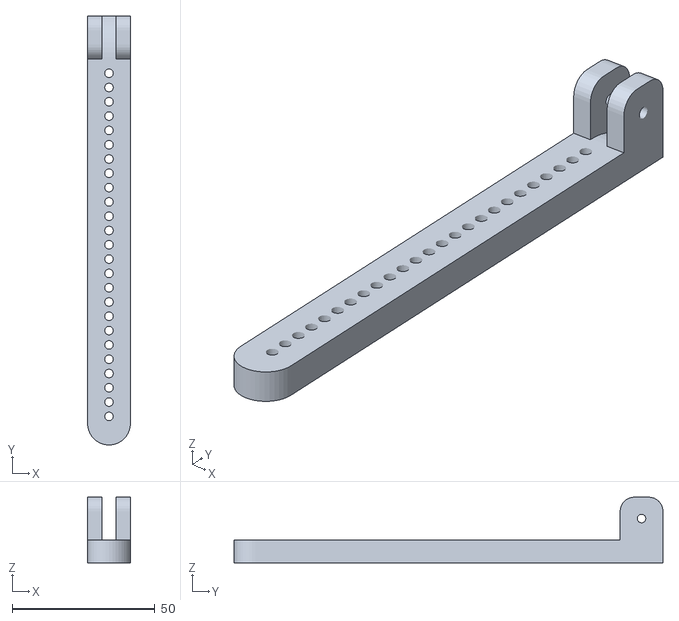
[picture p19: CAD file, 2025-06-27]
Hardware/STL/arm1.stl
15.0 x 150.0 x 23.0

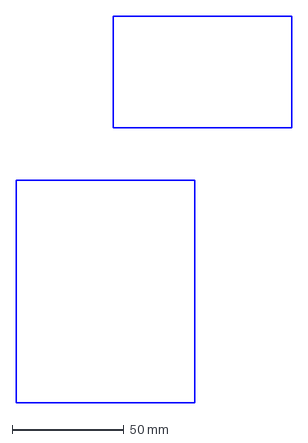
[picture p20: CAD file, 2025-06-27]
Hardware/DXF/tail-helper.dxf
123.5 x 173.4 mm

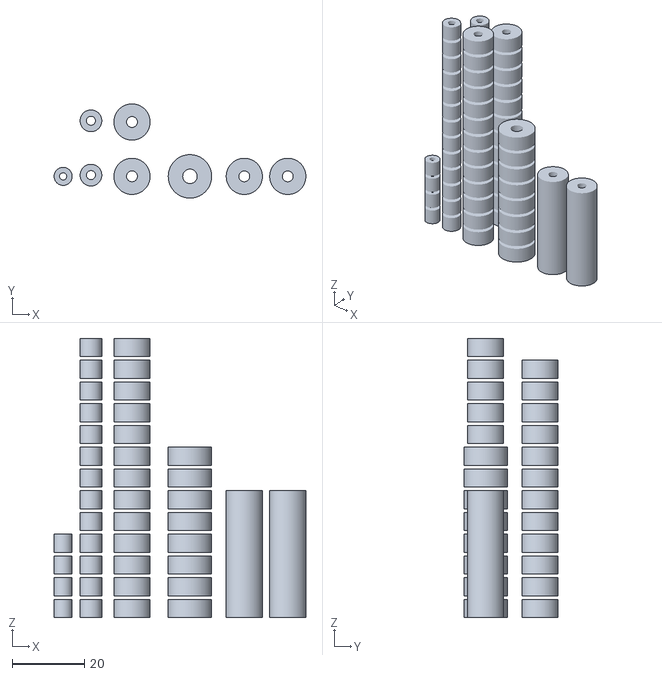
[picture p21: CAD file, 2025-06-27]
Hardware/STL/Spacers v4.stl
69.5 x 26.0 x 77.0

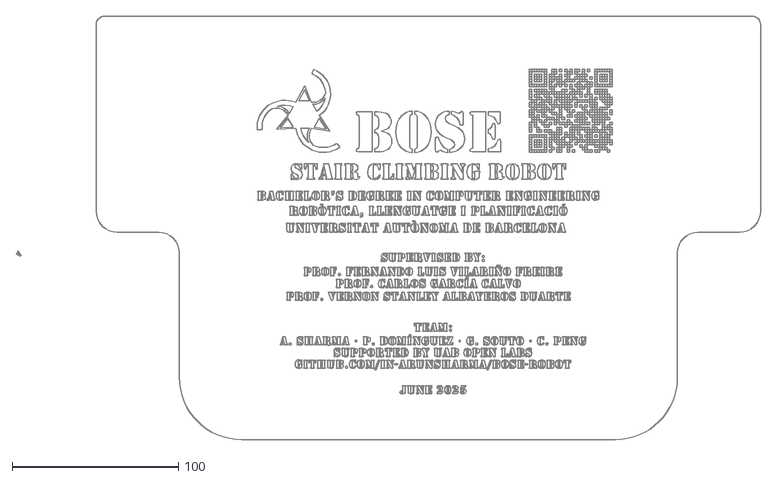
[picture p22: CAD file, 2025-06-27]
Hardware/DXF/Base.dxf
448.1 x 255.0

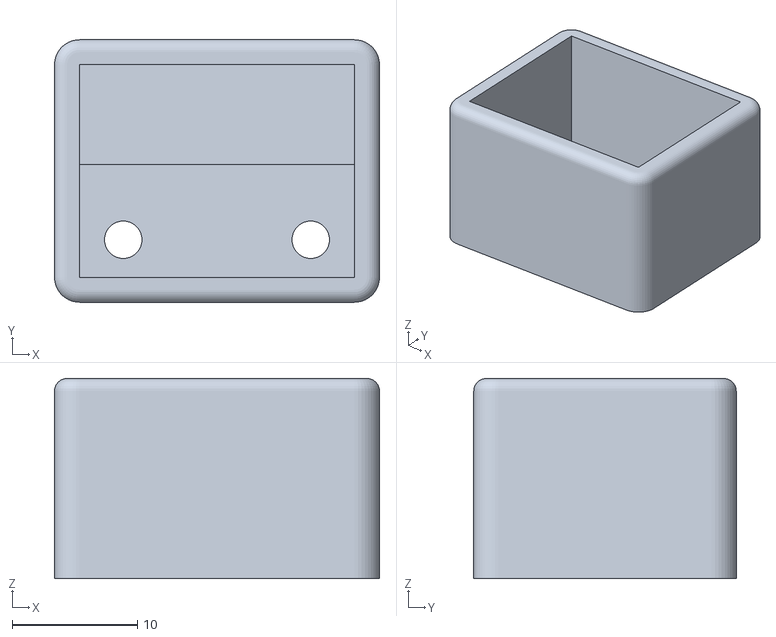
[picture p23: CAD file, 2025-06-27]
Hardware/STL/GyroscopeBottom.stl
26.0 x 21.0 x 16.0

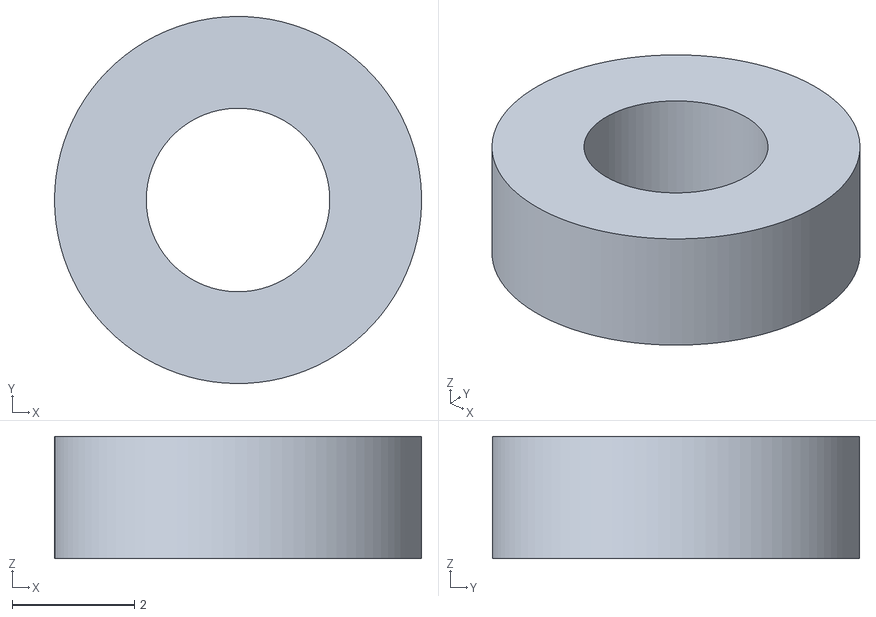
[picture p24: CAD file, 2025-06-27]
Hardware/STL/Body6_10copies.stl
6.00 x 6.00 x 2.00

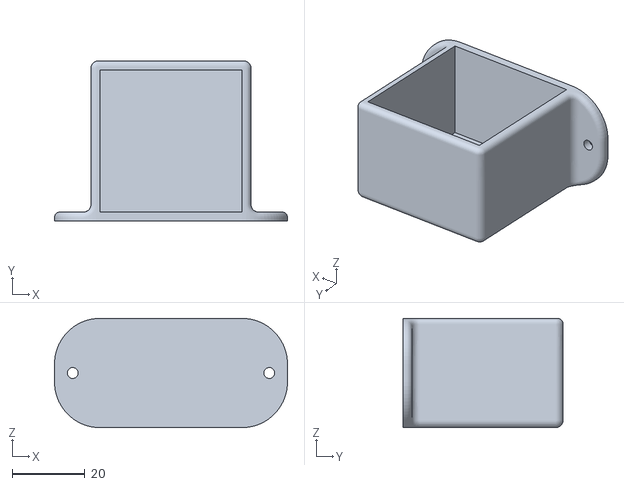
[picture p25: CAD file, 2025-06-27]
Hardware/STL/BatteryCover.stl
64.0 x 44.0 x 30.0

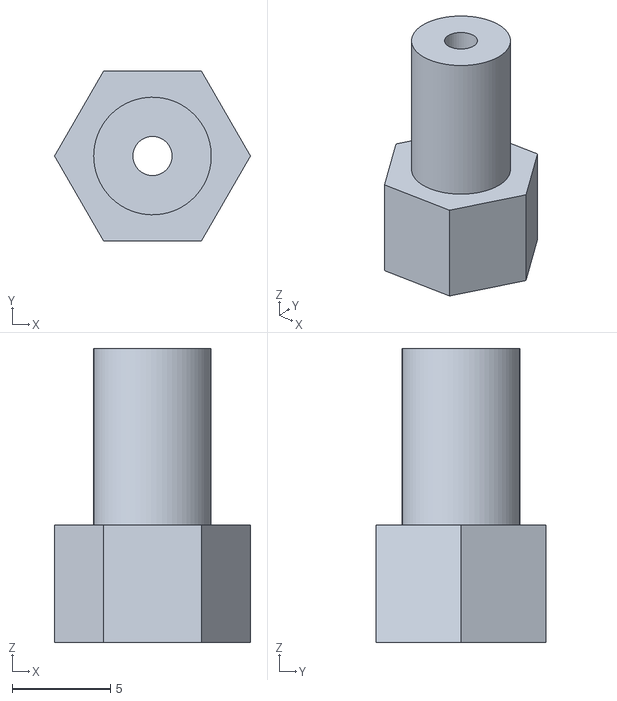
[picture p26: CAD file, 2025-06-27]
Hardware/STL/2i-6o_3copies.stl
10.0 x 8.66 x 15.0

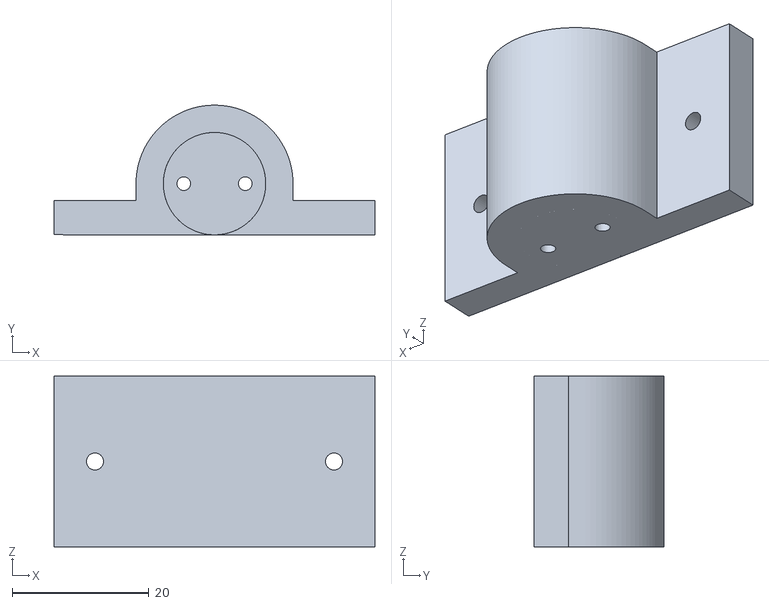
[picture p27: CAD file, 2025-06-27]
Hardware/STL/motorFront.stl
47.0 x 19.0 x 25.0

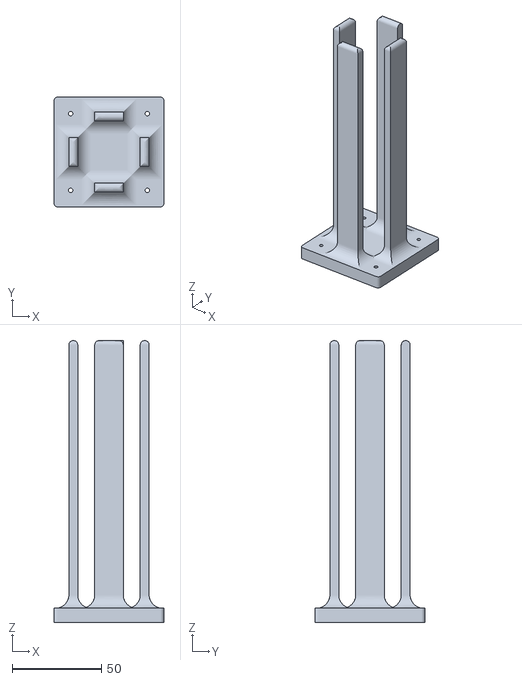
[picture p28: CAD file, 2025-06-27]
Hardware/STL/LidarUpperStand.stl
61.6 x 61.6 x 158.0

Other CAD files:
Hardware/STL/bosebot.gcode.3mf
Hardware/STL/wheel.stl
Hardware/STL/Tapa_Case_HCSR04_REV01.STL
Hardware/STL/Servo2.stl
Hardware/STL/3i-6o_10copies.stl
Hardware/STL/3i-8o_10copies.stl
Hardware/STL/BatteryCoverOpen.stl
Hardware/STL/Case_HCSR04_Ultrasonido_R01.STL
Hardware/STL/Hinge v3.stl
Hardware/STL/LidarBottomStand.stl
Hardware/STL/LockCover.stl
Hardware/STL/OctoPi_Camera_Lid.STL
Hardware/STL/PiSpacers_4copies.stl
Hardware/STL/PiSpacers_6copies.stl
Hardware/STL/Servos1.stl
Hardware/STL/Spacers30.stl
Hardware/STL/Spacers_8copies.stl
Hardware/STL/TopArmCAmera.stl
Hardware/STL/arm2.3.stl
Hardware/STL/boxSpacer_8copies.stl
Hardware/STL/fixedAxis.stl
Hardware/STL/lifter1.stl
Hardware/STL/lifter2.stl
Hardware/STL/motorBack.stl
Hardware/STL/pi_cam_v2_box.STL
Hardware/STL/servocase.stl

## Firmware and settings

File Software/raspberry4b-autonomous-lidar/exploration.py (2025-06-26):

#!/usr/bin/env python3
import smbus2, time, random
from rplidar import RPLidar
import numpy as np
import matplotlib.pyplot as plt
from threading import Thread

# Parámetros MD25
MD25_ADDR = 0x58
REG_L = 0
REG_R = 1
NEUTRAL = 128
MAX_SPEED = 200

bus = smbus2.SMBus(1)

def map_speed(pct):
    return int(NEUTRAL + (pct * (127/100)))

def set_speed(l_pct, r_pct):
    bus.write_byte_data(MD25_ADDR, REG_L, map_speed(l_pct))
    bus.write_byte_data(MD25_ADDR, REG_R, map_speed(r_pct))

# Exploración con LIDAR
PORT = '/dev/ttyUSB0'
lidar = RPLidar(PORT)
lidar.connect()
lidar.start_motor()
lidar.start()

GRID_SIZE = 200    # celdas
RES = 0.05         # 5 cm por celda
grid = np.zeros((GRID_SIZE, GRID_SIZE), dtype=int)
pos = np.array([GRID_SIZE//2, GRID_SIZE//2])
angle_robot = 0

plt.ion()
fig, ax = plt.subplots(figsize=(6,6))

def draw_map():
    ax.clear()
    ax.imshow(grid, cmap='Greys', origin='lower')
    ax.plot(pos[0], pos[1], 'ro')
    plt.pause(0.01)

def exploration():
    global pos, angle_robot

    for scan in lidar.iter_scans():
        # 1) mapeo
        for _, ang, dist in scan:
            if dist == 0: continue
            rad = np.deg2rad(ang + angle_robot)
            d = dist / 1000.0
            dx = int(d * np.cos(rad)/RES)
            dy = int(d * np.sin(rad)/RES)
            x = pos[0] + dx
            y = pos[1] + dy
            if 0 <= x < GRID_SIZE and 0 <= y < GRID_SIZE:
                grid[y, x] = 1

        # 2) frente libre?
        front = [d for _, ang, d in scan if abs((ang-0)%360) < 20]
        minf = min(front) if front else 1000
        if minf > 500:
            set_speed(50, 50)
            # avanzar
            pos += np.array([np.cos(np.deg2rad(angle_robot)),
                             np.sin(np.deg2rad(angle_robot))])
        else:
            set_speed(0, 0)
            # girar 90° aleatorio
            turn = random.choice([90, -90])
            angle_robot = (angle_robot + turn) % 360
            set_speed(0,0)
            time.sleep(0.5)

        draw_map()

def main():
    try:
        exploration()
    except KeyboardInterrupt:
        pass
    finally:
        set_speed(0, 0)
        lidar.stop()
        lidar.stop_motor()
        lidar.disconnect()
        bus.close()
        print("Exploración finalizada.")

if __name__=='__main__':
    main()

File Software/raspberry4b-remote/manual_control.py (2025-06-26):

#!/usr/bin/env python3
import time
import smbus2
import RPi.GPIO as GPIO
from adafruit_pca9685 import PCA9685
from board import SCL, SDA
import busio
from inputs import get_key

# === MD25 Motor Controller ===
MD25_ADDR    = 0x58
REG_SPEED1   = 0
REG_SPEED2   = 1
MD25_NEUTRAL = 128
SPEED_PCT    = 50

bus = smbus2.SMBus(1)

def map_speed(pct):
    """Convierte porcentaje [-100..100] a valor MD25 [1..255]"""
    return int(MD25_NEUTRAL + (pct * 127 / 100))

def set_md25(left_pct, right_pct):
    """Envía velocidad a MD25 en % para cada rueda"""
    l = map_speed(left_pct)
    r = map_speed(right_pct)
    bus.write_byte_data(MD25_ADDR, REG_SPEED1, l)
    bus.write_byte_data(MD25_ADDR, REG_SPEED2, r)

# === Retractable Wheels (L298N) ===
GPIO.setmode(GPIO.BCM)
MOTOR_PINS = {
    'EN_A': 13, 'IN1': 6,  'IN2': 5,
    'EN_B': 12, 'IN3': 16, 'IN4': 26
}
for pin in MOTOR_PINS.values():
    GPIO.setup(pin, GPIO.OUT)

pwmA = GPIO.PWM(MOTOR_PINS['EN_A'], 100)
pwmB = GPIO.PWM(MOTOR_PINS['EN_B'], 100)
pwmA.start(0)
pwmB.start(0)
RETRACT_SPEED = 30  # % duty cycle

def set_retract(direction):
    if direction == 'forward':
        GPIO.output(MOTOR_PINS['IN1'], GPIO.HIGH)
        GPIO.output(MOTOR_PINS['IN2'], GPIO.LOW)
        GPIO.output(MOTOR_PINS['IN3'], GPIO.HIGH)
        GPIO.output(MOTOR_PINS['IN4'], GPIO.LOW)
        pwmA.ChangeDutyCycle(RETRACT_SPEED)
        pwmB.ChangeDutyCycle(RETRACT_SPEED)
    elif direction == 'backward':
        GPIO.output(MOTOR_PINS['IN1'], GPIO.LOW)
        GPIO.output(MOTOR_PINS['IN2'], GPIO.HIGH)
        GPIO.output(MOTOR_PINS['IN3'], GPIO.LOW)
        GPIO.output(MOTOR_PINS['IN4'], GPIO.HIGH)
        pwmA.ChangeDutyCycle(RETRACT_SPEED)
        pwmB.ChangeDutyCycle(RETRACT_SPEED)

def stop_retract():
    pwmA.ChangeDutyCycle(0)
    pwmB.ChangeDutyCycle(0)

# === Servos (PCA9685) ===
i2c = busio.I2C(SCL, SDA)
pca = PCA9685(i2c)
pca.frequency = 50
SERVO_UP   = 500  # 0°
SERVO_DOWN = 150  # 180°

def move_servos(pulse):
    pca.channels[0].duty_cycle = pulse * 16
    pca.channels[8].duty_cycle = pulse * 16

# === MD25 Initialization ===
# modo 0 = control por registro, comando 50 = reset encoder
bus.write_byte_data(MD25_ADDR, 15, 0)
bus.write_byte_data(MD25_ADDR, 16, 50)
print("MD25 Initialized")

print("  Control manual:")
print("  WASD: mover MD25")
print("  Flechas: ruedas retráctiles")
print("  O/L: subir/bajar servos")
print("  E: salir y parar todo")

REFRESH_RATE = 0.03
pressed = set()

try:
    while True:
        events = get_key()
        for e in events:
            if e.ev_type == "Key":
                if e.state == 1:
                    pressed.add(e.code)
                else:
                    pressed.discard(e.code)

        # — MD25 principal (W/A/S/D) —
        if 'KEY_W' in pressed:
            set_md25(SPEED_PCT, SPEED_PCT)
        elif 'KEY_S' in pressed:
            set_md25(-SPEED_PCT, -SPEED_PCT)
        elif 'KEY_A' in pressed:
            set_md25(-SPEED_PCT, SPEED_PCT)
        elif 'KEY_D' in pressed:
            set_md25(SPEED_PCT, -SPEED_PCT)
        else:
            set_md25(0, 0)

        # — Ruedas retráctiles (flechas) —
        if 'KEY_UP' in pressed:
            set_retract('forward')
        elif 'KEY_DOWN' in pressed:
            set_retract('backward')
        else:
            stop_retract()

        # — Servos (O/L) —
        if 'KEY_O' in pressed:
            move_servos(SERVO_UP)
        elif 'KEY_L' in pressed:
            move_servos(SERVO_DOWN)

        # — Exit (E) —
        if 'KEY_E' in pressed:
            break

        time.sleep(REFRESH_RATE)

except KeyboardInterrupt:
    pass

finally:
    print("Parando todo y limpiando recursos...")
    set_md25(0, 0)
    stop_retract()
    GPIO.cleanup()
    pca.deinit()
    bus.close()
    print("Listo.")

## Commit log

2025-05-03 Added initial files
    [Motor_frontCase.stl]
2025-06-24 Update Paper.md (4.2 wheel configuration)
2025-06-26 Remote controll raspberry4b & visual slam readme
2025-06-26 Add Wheel Diagram
2025-06-26 Rename Wheel Diagram.jpg to WheelDiagram.jpg
2025-06-26 Autonomus lidar movment bose
2025-06-27 retractable wheel
2025-06-27 stl and dxp added
    [2i-6o_3copies.stl, 3i-6o_10copies.stl, 3i-8o_10copies.stl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]
